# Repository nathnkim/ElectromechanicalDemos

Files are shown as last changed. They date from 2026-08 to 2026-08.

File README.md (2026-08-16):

# Base excitation demo assembly and test video:  https://www.youtube.com/watch?v=d6ixO5XXAhE
# Position control assembly and test video: https://www.youtube.com/watch?v=w2qYwhUiyq8
This repo contains the source files and documentation for the SDoF demo platform that I originally designed and built for MECHENG 360 at the University of Michigan - Ann Arbor, under Dr. Jeffrey Koller.

The SDoF demo platform consists of a brushed DC motor on an aluminum testbed which can be swapped between a mass-spring-damper base excitation demo and linear position control PID tuning demo.

Drive base:


Power module:


Base excitation demo:


Linear position control demo:


This version of SDoF is a good start, but it could benefit from further iteration. Suggested next steps to improve the demo are listed in the "Next Steps" document in this directory. This documentation was originally hosted in Google Drive, so many of the documentation files exist as Word doc files as an artifact of the download from drive > upload to Github migration. I've included full CAD models of the original design, complete with a comprehensive bill of materials and part numbering scheme. I've also included the code that ran on these demos (definitely some bugs to work out) as well as wiring diagrams.

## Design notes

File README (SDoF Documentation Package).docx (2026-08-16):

Nathan Kim (nathnkim@umich.edu)

2/6/2024

This directory contains the documentation for the SDoF demo platform originally designed and built for MECHENG 360 at the University of Michigan - Ann Arbor, under Dr. Jeffrey Koller.

This version of SDoF is a good start, but could benefit from further iteration. Suggested next steps to improve the demo are listed in the “Next Steps” document in this directory. I’ve included full CAD models of the original design, complete with a comprehensive bill of materials and part numbering scheme. I’ve also included the code that ran on these demos (definitely some bugs to work out) as well as wiring diagrams. To cover assembly of the demos, I made a couple of videos in the “How to Build SDoF” folder which, as well as a fastener guide document that shows what bolt goes where.

Definitely feel free to reach out to me at nathnkim@umich.edu if anything is confusing!

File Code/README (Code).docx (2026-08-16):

sdof_freq_sweep.ino is the program that runs on the frequency sweep module, and sdof_control.ino is the program that runs on the control module. Both run on an Arduino Micro (https://store.arduino.cc/products/arduino-micro). sdof_control.ino needs some work to write the interrupt service routines to safe the demo if the pointer slams into either of the limit switches. Additionally, the controls demo is currently pretty buggy for reasons unknown- perhaps the code needs to be made more robust.

To edit these files, and upload them to the boards, I recommend using the Arduino IDE (https://www.arduino.cc/en/software). Download the FOLDERS of the code as they are in this directory, since the Arduino IDE requires that .ino files be in a folder with the same name in order to open them.

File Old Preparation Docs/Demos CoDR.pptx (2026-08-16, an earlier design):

## ME 360 Teaching Demos

Conceptual Design Review
Nathan Kim

Note - this deck was a preliminary iteration of ideas presented to the FA2023 instructional team for feedback. Saving it for posterity; note the design has changed quite a bit since this presentation was delivered.
-Nathan Kim 1/4/2024

## Frequency Response Demo - “ME 360 Single Degree of Freedom”

Overview:
- Single degree of freedom mass-spring-damper with base excitation
- Motion input provided by slider-crank mechanism driven by 12V DC motor
- User input:
  - Knob to vary excitation frequency
  - Easy to change masses, springs with different constants, dampers with different constants
Learning Objectives:
- Students can vary system parameters and sweep frequencies in a very tactile way to build an intuitive understanding of second order system frequency response

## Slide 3

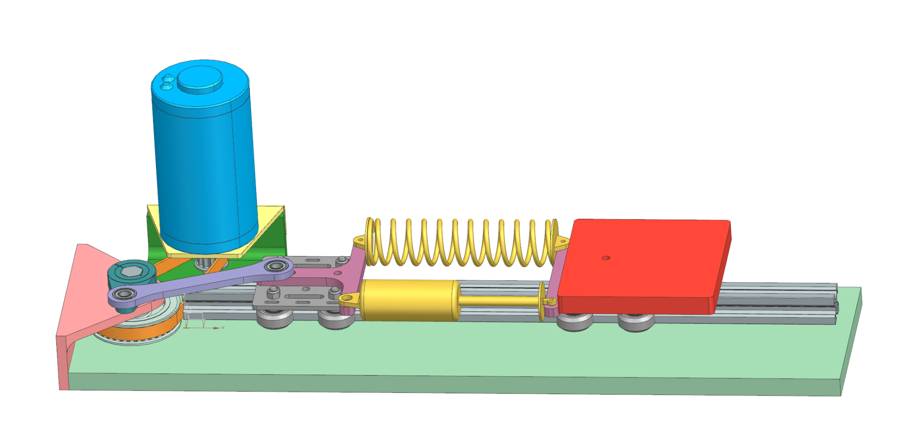
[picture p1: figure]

20” long x 5” wide, 0.5” thick Al plate base with plenty of room to be clamped to a table

Drive system is modular; belt is tensionable through pivoting of this module

SDoF Mechanical Assembly

System parameters fastened with bolts + wingnuts for relative ease of adjustment

Square mass plates can be stacked

Performance RC car springs and dampers

Al extrusion linear rail + gantry plates with ball bearings constrain motion along DoF

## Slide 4

SDoF Mechanical Assembly

Pocketed base plate allows for underside hardware mounting while still sitting flush on a surface

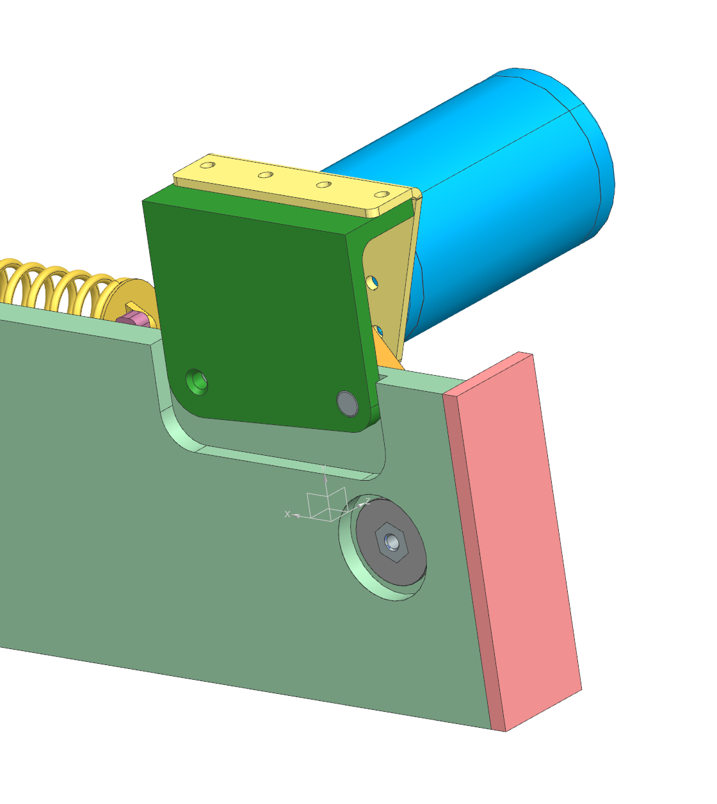
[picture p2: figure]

Precision dowel pin provides pivot point for drive module, allowing for belt tensioning

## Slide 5

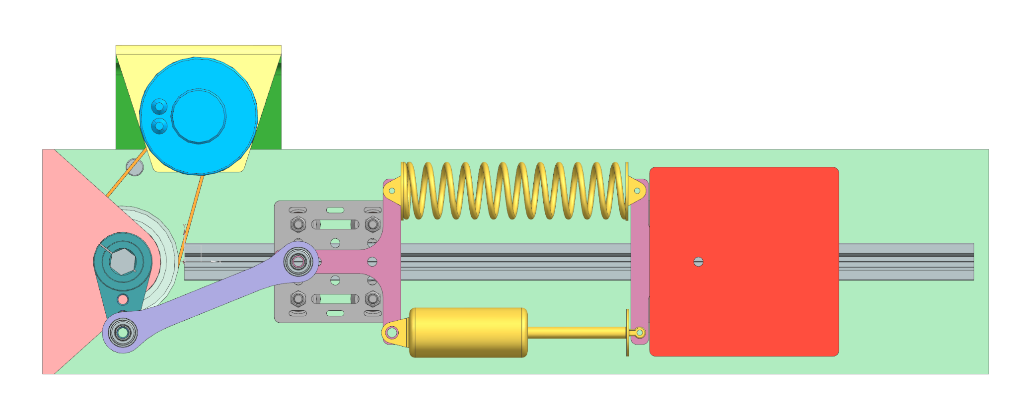
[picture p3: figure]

SDoF Mechanical Assembly

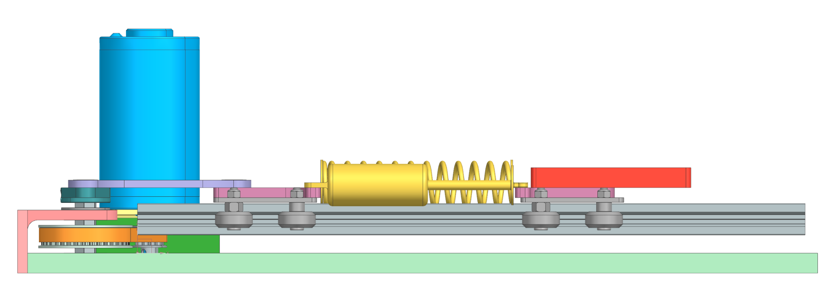
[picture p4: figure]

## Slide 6

SDoF Mechanical Assembly

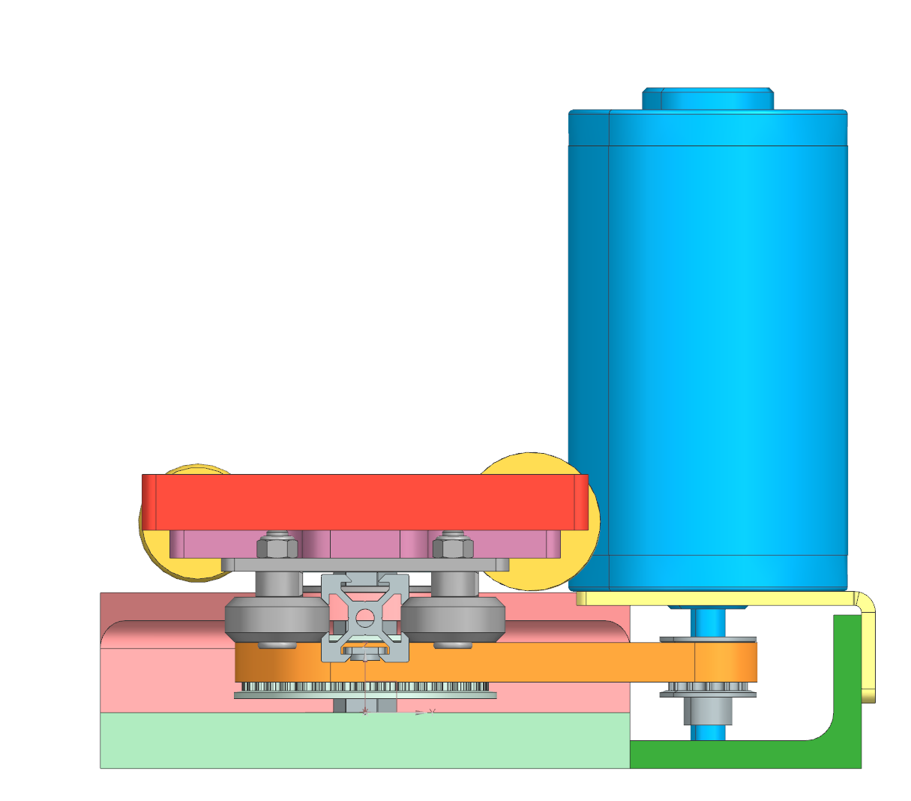
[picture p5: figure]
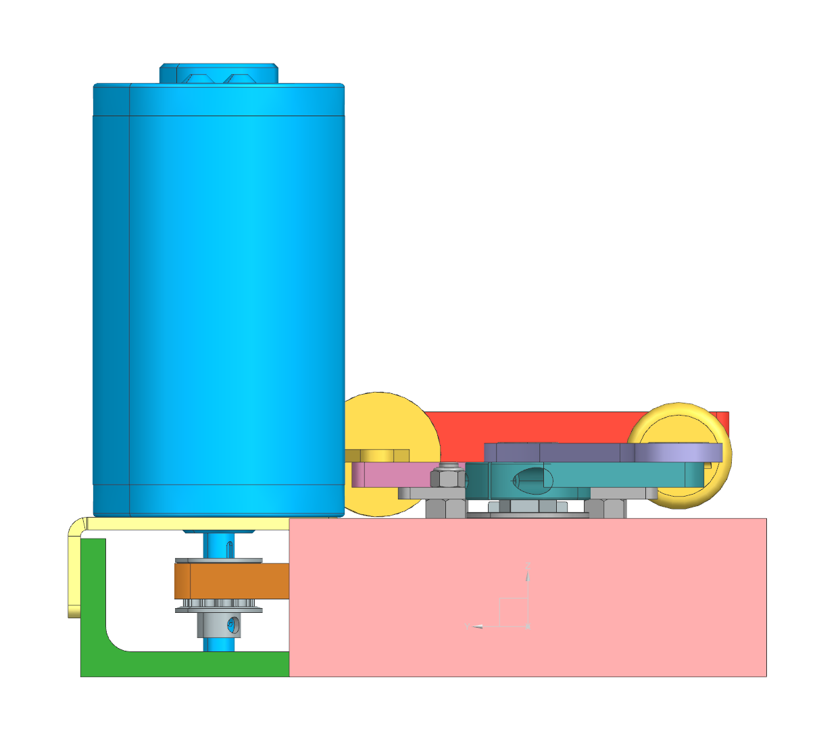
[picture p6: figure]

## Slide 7

All electronic components are available as generics on Amazon

SDoF Electronics

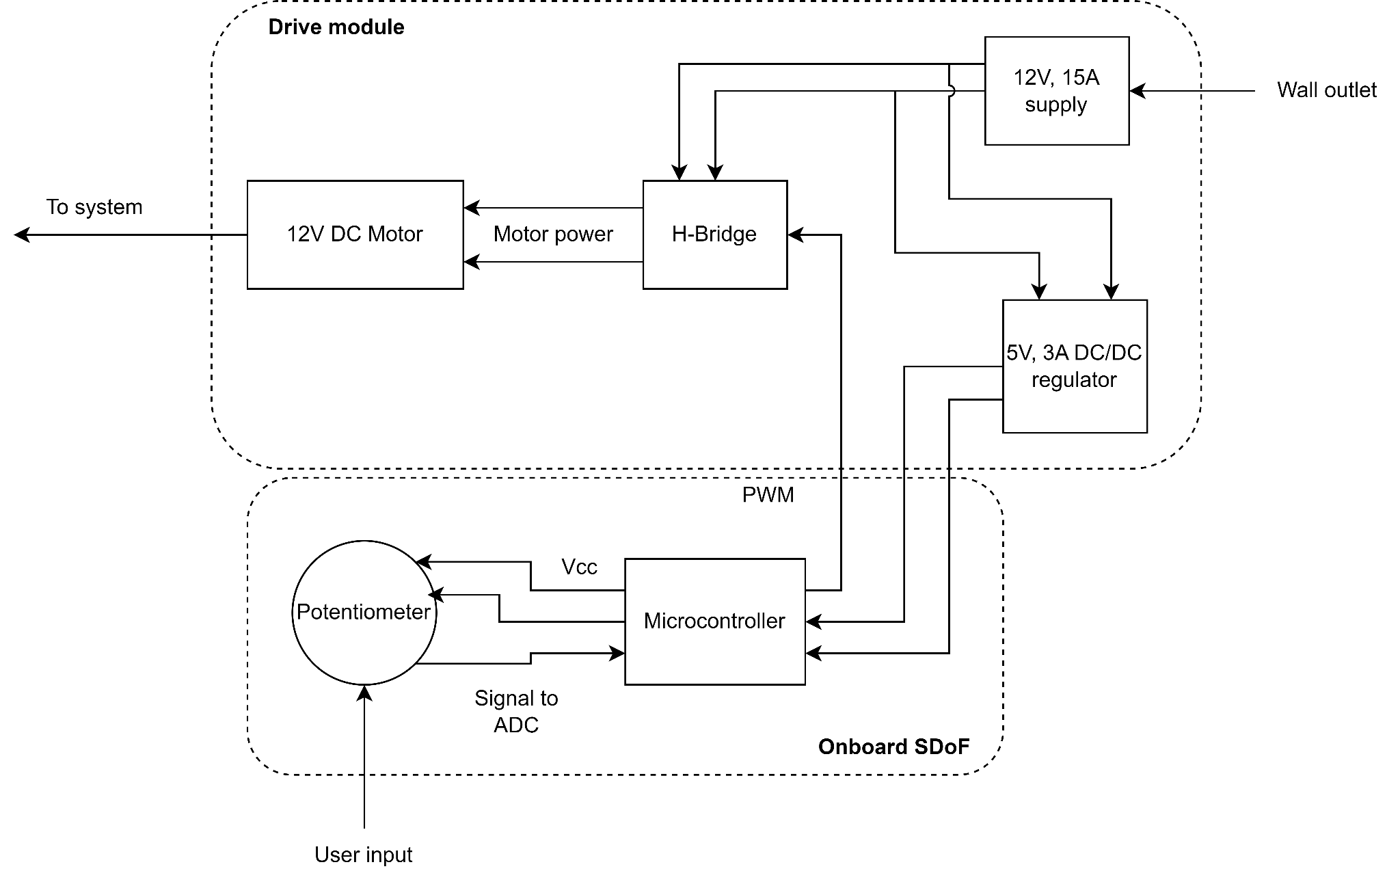
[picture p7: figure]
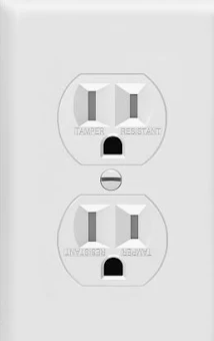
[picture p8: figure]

Drive module allows drop-in compatibility with control box demo

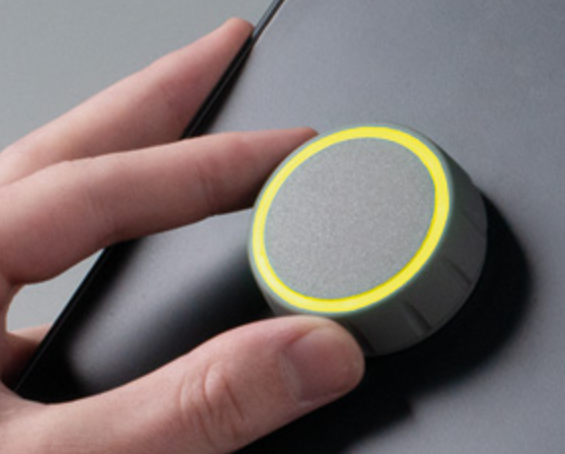
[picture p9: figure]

Enclosures will be designed/fabricated after function is verified

## PID Controller Demo - “ME 360 Point-a-Tron” - awaiting better alt

Overview:
- Single degree of freedom position control
- Drive module shared with SDoF demo
- User input:
  - Knobs to adjust controller gains
  - Hand positioning of reference position
Learning Objectives:
- Students can vary controller gains in a tactile way to build an intuitive understanding of how PID gains affect controller performance

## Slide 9

Exact same drive base as SDoF, so only 1 needs to be built

Point-a-Tron Mechanical Assembly

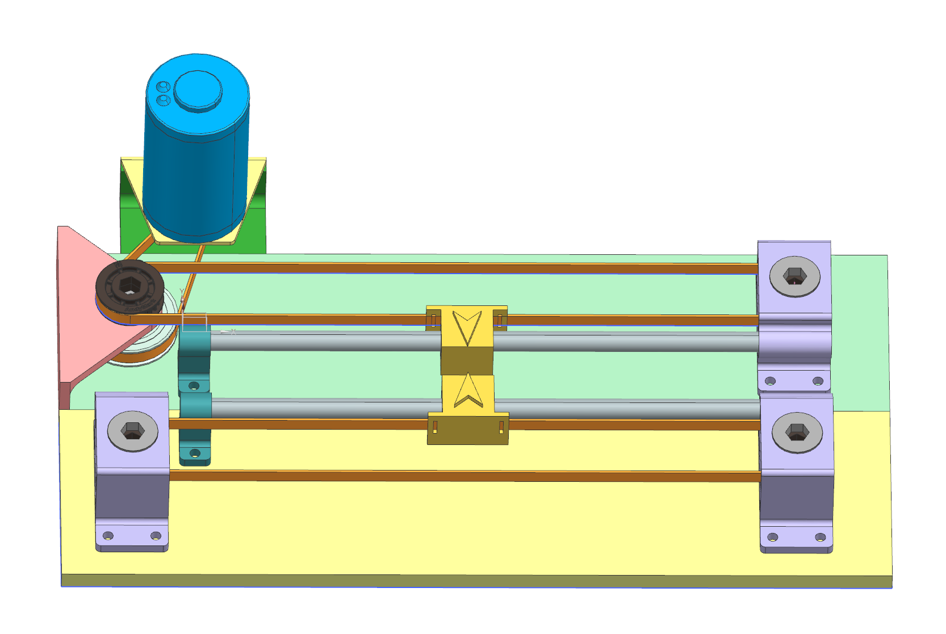
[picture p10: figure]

Belt-driven 3D printed pointer rides motion rail

Low loads means all support structures can be 3D printed

Reference input rail structure is a mirror of controlled output structure

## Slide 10

Point-a-Tron Mechanical Assembly

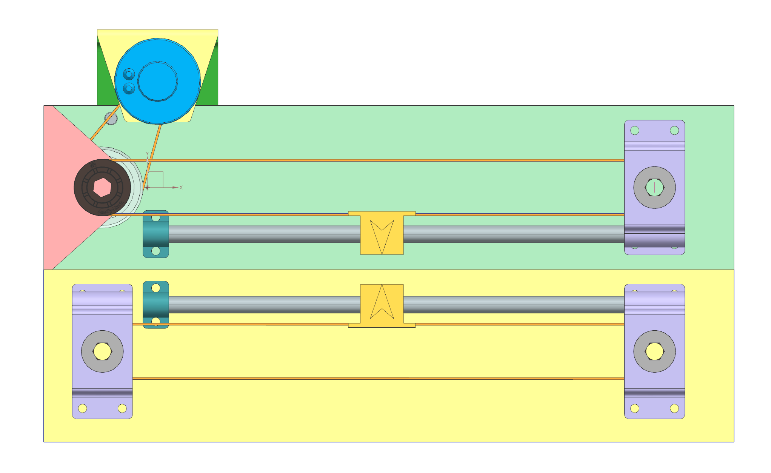
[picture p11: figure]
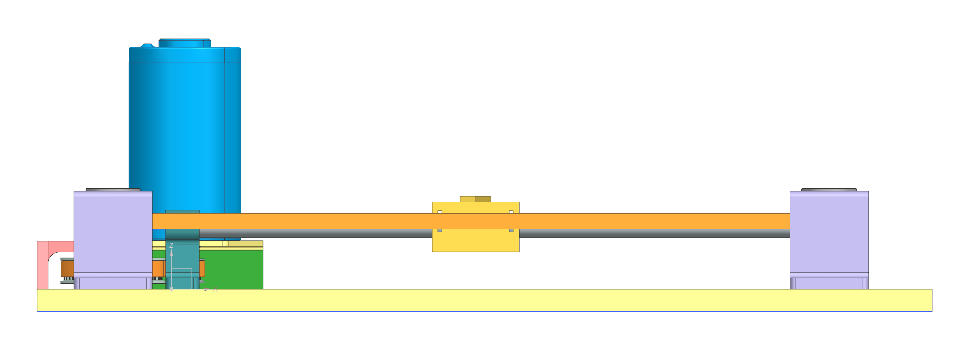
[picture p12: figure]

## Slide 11

Point-a-Tron Mechanical Assembly

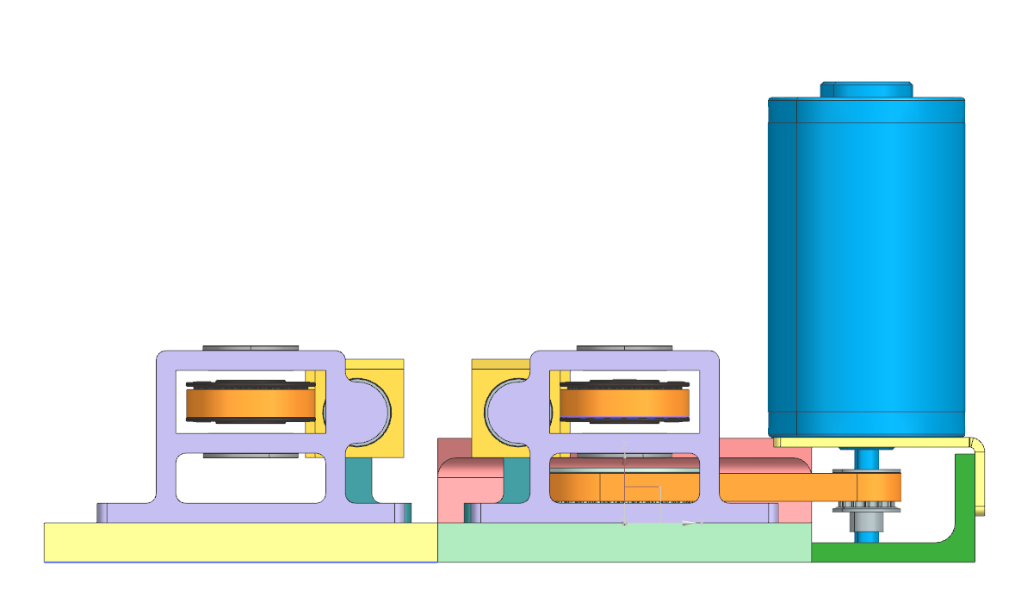
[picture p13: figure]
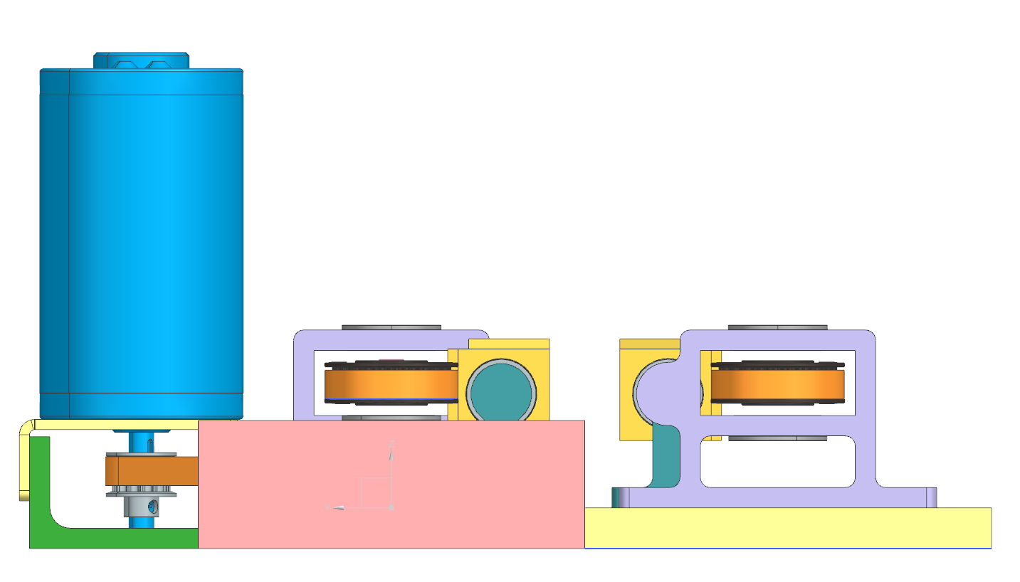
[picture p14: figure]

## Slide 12

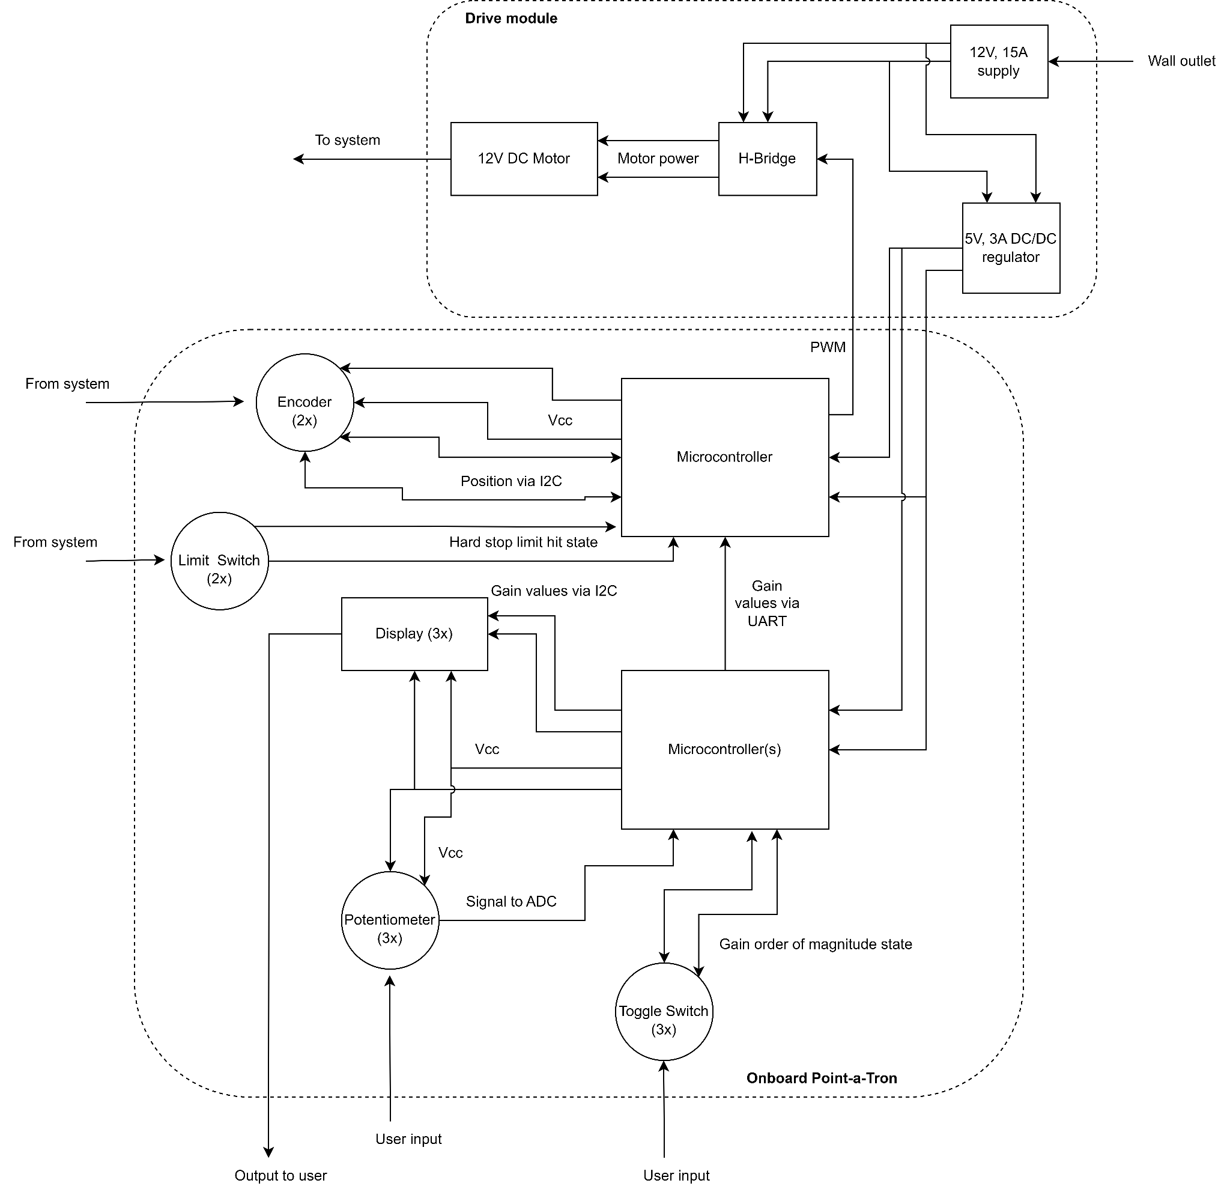
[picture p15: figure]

Point-a-Tron Electronics

Lots of displays to drive, inputs to deal with, so baselining multiple microcontrollers- might be able to get around this by daisy-chaining I2C

Enclosures will be designed/fabricated after function is verified

## Path Forward

- Incorporate feedback
- Finishing touches on CAD
  - Final hole patterns and fastener sizing
  - Higher fidelity spring/damper models
  - Switch/knob mounting structures
- Cut a BoM + get parts ordered- order ready to go out by next Friday for SDoF parts

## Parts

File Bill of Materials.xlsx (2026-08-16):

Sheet: Start Here
Introduction
This sheet contains the Bill of Materials (BOM) for the first revision design of SDoF demonstration platform. Each major assembly has its own sheet tab below. The CAD is split into major assemblies which include the drive base, which is common between the frequency and controller demos (which themselves are major assemblies) as well as the power module, which is the power supply that feeds the drive base. These sheets contain the individual bills of material for each major assembly, using part numbers that match CAD, and the sheet tab names include the CAD part number/filename as well. COTS parts have numbers that allow you to trace back the actual part to the supplier by simply copy/ pasting the part number into your url bar and also have purchase links listed. The sheets also include manufacturing notes where applicable. Note SDOF-FREQ-A01 and SDOF-CTRL-A01 contain subassemblies, which exist due to how the electronics are modularized. Their sheets contain SDOF-FREQ-A02 and SDOF-CTRL-A02 respectively, and both include SDOF-A01, all of which have their own wiring schematics. Also note that there are common parts (fasteners, connectors, etc) between major assemblies. These kinds of components often come in packs, so if you buy a pack for one assembly, it may cover the qty needed for other asssemblies. Double check the QTY columns when buying packs. Similarly, there are parts that use the same stock, like the axles. For these, one long piece of stock can be used to make every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
How to interpret part numbers: Commercial-off-the-shelf (COTS): SUPPLIER-SUPPLIERPART. Items that were bought and used more or less as is. -> Example: the motor is AndyMark product AM-0255, so in this scheme its PN is ANDYMARK-AM-0255 Custom designed/built parts: ASSEMBLY-FILETYPE#(L/R). Parts that were custom designed and built. Part filetypes are either assemblies (contain components, -AXXX tag) or components (single solid body, -CXXXX tag). If the part has a mirror pair, it well be designated by the L or R tag for left or right. -> Example: the drive base plate is in the SDOF assembly, is a component file, and is component #1, so in this scheme its PN is SDOF-C01. -> Example: the major assembly for the power module is the SDOF-PWR assmebly, is an assembly file, and is the top level assembly (#1), so in this scheme its PN is SDOF-PWR-A01 -> Example: the control module subassembly is in the SDOF-CTRL assembly, it is an assembly file, and is the first subassembly (#2), so in this scheme its PN is SDOF-CTRL-A02 -> Example: the spring end rotation constraint is in the SDOF-FREQ assembly, is a component file, is component #8, and has a mirror, so in this scheme the mirror pair PNs are SDOF-FREQ-C08L and SDOF-FREQ-C08R.
Major Assemblies

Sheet: SDOF-A01 (Drive Base)
Drive Base (PN: SDOF-A01)
Part Description | Part Number (PN) | QTY (per assembly) | Included in CAD for SDOF-A01? | Source | MFG notes
Base plate | SDOF-C01 | 1 | Y | Stock: https://www.mcmaster.com/8975K217-9140T109/ | Custom machined; manual mill, end holes match drilled using SDOF-C02
Crankshaft bracket | SDOF-C02 | 1 | Y | Stock: https://www.mcmaster.com/8982K63-8982K631/ | Custom machined; manual mill + hand shaped
Motor bracket-base plate bracket | SDOF-C03 | 1 | Y | Stock: https://www.mcmaster.com/8982K63-8982K631/ | Custom machined; manual mill + hand shaped
Crankshaft | SDOF-C04 | 1 | Y | Stock: https://www.andymark.com/products/1-2-in-7075-aluminum-hex-shaft-stock?Length=3%20ft.%20(am-2291-3)&quantity=1 | Custom machined; manual lathe
1/8" hex spacer | SDOF-C05 | 3 | Y | 3D printed PLA | 3D printed PLA
Cable-base mount | SDOF-C06 | 2 | Y | 3D printed PLA | 3D printed PLA
Jack-H-bridge bracket | SDOF-C07 | 1 | Y | 3D printed PLA | 3D printed PLA
XT60-H-bridge bracket | SDOF-C08 | 1 | Y | 3D printed PLA | 3D printed PLA
Cable-H-bridge mount | SDOF-C09 | 1 | Y | 3D printed PLA | 3D printed PLA
Drive wire cover | SDOF-C10 | 1 | Y | 3D printed PLA | 3D printed PLA
Name plate base | SDOF-C11 | 1 | No, but file exists | 3D printed PLA | 3D printed PLA - ditched this as I didnt like the way it looked in real life
Name plate | SDOF-C12 | 1 | No, but file exists | From scrap | Laser cut/engraved- ditched this as I didnt like the way it looked in real life
Drive cable | SDOF-C13 | 1 | N | From scrap | Hacked together from an old USB cable, spliced in female JST SMR-04V connector (not in CAD)
1/4-20 socket cap machine screw | MCMASTER-92949A539 | 14 | N - see fastener install guide | COTS: https://www.mcmaster.com/92949A539/
1/4 bore washer | MCMASTER-90107A029 | 1 | N - see fastener install guide | COTS: https://www.mcmaster.com/90107A029/
M3 machine screw + nut pairs | AMAZON-B01NBOCXHE | 2 | N - see fastener install guide | COTS: https://www.amazon.com/gp/product/B01NBOCXHE/ref=ppx_yo_dt_b_asin_title_o01_s00?ie=UTF8&th=1
Dowel pin | MCMASTER-98381A619 | 1 | Y | COTS: https://www.mcmaster.com/98381A619/
1/2" hex bearings | ANDYMARK-AM-2986 | 2 | Y | COTS: https://www.andymark.com/products/0-5-in-hex-id-1-125-in-od-shielded-flanged-bearing-fr8zz-hexhd
Motor | ANDYMARK-AM-0255 | 1 | Y | COTS: https://www.andymark.com/products/2-5-in-cim-motor
Motor shaft key | ANDYMARK-AM-1121 | 1 | N - see fastener install guide | COTS: https://www.andymark.com/products/2x2x10-mm-machine-key-steel
Motor mount bracket | ANDYMARK-AM-4244 | 1 | Y | COTS: https://www.andymark.com/products/bearing-and-motor-mount-bracket
Motor mount bolts | MCMASTER-91251A342 | 2 | N - see fastener install guide | COTS: https://www.mcmaster.com/91251A342/
Belt | ANDYMARK-AM-4902 | 1 | Y | COTS: https://www.andymark.com/products/9-mm-wide-5-mm-pitch-htd-timing-belts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
Pinion | ANDYMARK-AM-3263 | 1 | Y | COTS: https://www.andymark.com/products/12-tooth-5mm-htd-cim-bore-pulley-with-flanges
Drive pulley | VEX-217-3231 | 1 | Y | COTS: https://www.vexrobotics.com/htdpulleys.html#attr-vex_drawings
H-bridge | AMAZON-B07SH6BX97 | 1 | Y | COTS: https://www.amazon.com/gp/product/B07SH6BX97
XT60 connector | AMAZON-B07233RVL6 | 1 | Y | COTS: https://www.amazon.com/Female-Bullet-Connectors-Shrink-Battery/dp/B07233RVL6/ | Had to carve off some of the embossed symbols to fit the brackets with an exacto knife
Barrel Jack | AMAZON-B091PS6XQ4 | 1 | Y | COTS: https://www.amazon.com/gp/product/B091PS6XQ4/
Not included in BoM:
Assorted wire/heat shrink for drive cable installation

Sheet: SDOF-PWR-A01 (Power Module)
Power Module (PN: SDOF-PWR-A01)
Part Description | Part Number (PN) | QTY (per assembly) | Included in CAD for SDOF-PWR-A01? | Source | MFG notes
12v power supply | AMAZON-B08LDC41B6 | 1 | Y | COTS: https://www.amazon.com/Universal-Regulated-Switching-Converter-Transformer/dp/B08LDC41B6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 | Used crimp spade connectors for the screw terminal connections
Toggle switch | AMAZON-B078KBC5VH | 1 | Y | COTS: https://www.amazon.com/Nilight-Rocker-Toggle-Switch-Waterproof/dp/B078KBC5VH?sp_csd=d2lkZ2V0TmFtZT1zcF9hdGY
12v-5v DC-DC converter | AMAZON-B07Y2V1F8V | 1 | Y | COTS: https://www.amazon.com/Converter-Voltage-Waterproof-Regulator-Step-Down/dp/B07Y2V1F8V
Inline fuse holder | AMAZON-B08K3M554K | 1 | N - see wiring schematic for placement | COTS: https://www.amazon.com/dp/B08K3M554K?ref=ppx_yo2ov_dt_b_product_details&th=1
10A blade fuse | AMAZON-B07G33XCHM | 1 | N - see wiring schematic for placement | COTS: https://www.amazon.com/dp/B07G33XCHM?psc=1&ref=ppx_yo2ov_dt_b_product_details
Power supply cover | SDOF-PWR-C01 | 1 | Y | 3D printed PLA | 3D printed PLA, used cyanoacrylate to glue M3 nuts into recesses before assembly. Took some fiddling to get nice mate between this part and the power supply.
Small cable gland | SDOF-PWR-C02 | 2 | Y | 3D printed PLA | 3D printed PLA
Large cable gland | SDOF-PWR-C03 | 1 | Y | 3D printed PLA | 3D printed PLA
XT60 connector (male) | AMAZON-B07233RVL6 | 1 | N - see wiring schematic for placement | COTS: https://www.amazon.com/Female-Bullet-Connectors-Shrink-Battery/dp/B07233RVL6/
DC barrel jack (male) | AMAZON-B08SJM2G52 | 1 | N - see wiring schematic for placement | COTS: https://www.amazon.com/Socket-Threaded-Connector-Adapter-Dustproof/dp/B08SJM2G52/
M3 machine screw + nut pairs | AMAZON-B01NBOCXHE | 3 | N - see fastener guide | COTS: https://www.amazon.com/gp/product/B01NBOCXHE/ref=ppx_yo_dt_b_asin_title_o01_s00?ie=UTF8&th=1
Not included in BoM
Mounting hardware for the toggle switch (came included with the component purchased)
Male 110V wall plug to wire in, I bought this at a hardware store

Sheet: SDOF-FREQ-A01 (Frequency Respon
Frequency Response Demo (PN: SDOF-FREQ-A01)
Part Description | Part Number (PN) | QTY (per assembly) | Included in CAD for SDOF-FREQ-A01? | Source | MFG notes
Drive base | SDOF-A01 | 1 | Y | Custom assembly | See SDOF-A01 sheet and documentation
Crank | SDOF-FREQ-C01 | 1 | Y | Scrap steel & shaft collar: https://www.mcmaster.com/7552K5/ | Shaped and welded steel plate to shaft collar, then drilled and tapped holes
Connecting rod | SDOF-FREQ-C02 | 1 | Y | Scrap stainless steel | Bored bearing seats on manual mill, shaped by hand
Spring/damper bracket | SDOF-FREQ-C03 | 2 | Y | Stock: https://www.mcmaster.com/89015K235/ | Lasercut from 0.125" thick 6061 sheet
Rail spacer | SDOF-FREQ-C04 | 2 | Y | Scrap aluminum | Shaped and drilled by hand
Crank-Connecting rod spacer | SDOF-FREQ-C05 | 1 | Y | 3D printed PLA | 3D printed PLA
Connecting rod-gantry plate spacer | SDOF-FREQ-C06 | 1 | Y | 3D printed PLA | 3D printed PLA
Spring end plate | SDOF-FREQ-C07 | 2 | Y | Scrap aluminum | Lasercut from 0.125" thick 6061 sheet
Left spring end rotation constraint | SDOF-FREQ-C08L | 1 | Y | 3D printed PLA | 3D printed PLA
Right spring end rotation constraint | SDOF-FREQ-C08R | 1 | Y | 3D printed PLA | 3D printed PLA
Bolt spacer | SDOF-FREQ-C09 | 4 | Y | 3D printed PLA | 3D printed PLA
Spring | AMAIN-PRO6275-00-Spring | 1 | Y | COTS: https://www.amainhobbies.com/proline-5-powerstroke-xt-shocks-pro6275-00/p479230 | Vendor PN is PRO6275-00, which comes with spring and damper integrated. Given "Spring" tag since whole shock disassembled to isolate the spring. CAD model is very approximate.
Damper | AMAIN-PRO6275-00-Damper | 1 | Y | COTS: https://www.amainhobbies.com/proline-5-powerstroke-xt-shocks-pro6275-00/p479230 | Vendor PN is PRO6275-00, which comes with spring and damper integrated. Given "Damper" tag since whole shock disassembled to isolate the damper. Two packs of this product were bough to have 4 dampers that could be filled with different viscosities of shock fluid (https://www.amainhobbies.com/team-losi-racing-silicone-shock-oil-six-pack-20-25-30-35-40-45wt-2oz-tlr74020/p252365). Used a youtube video to figure out how to fill the dampers with oil and bleed them properly- search "how to bleed and fill RC car shocks". CAD model is very approximate.
1/4-20 socket cap machine screw | MCMASTER-92949A539 | 8 | N - see fastener install guide | COTS: https://www.mcmaster.com/92949A539/
M3 machine screw + nut pairs | AMAZON-B01NBOCXHE | 2 | N - see fastener install guide | COTS: https://www.amazon.com/gp/product/B01NBOCXHE/ref=ppx_yo_dt_b_asin_title_o01_s00?ie=UTF8&th=1
M5 socket cap machine screw | MCMASTER-92095A218 | 2 | N - see fastener install guide | COTS: https://www.mcmaster.com/92095A218/ | I had to chop em down a bit smaller on the bandsaw to fit. Note- I bought these from Stadium Hardware in Ann Arbor, much cheaper to buy 2 than a pack on McMaster
M5 threaded plates | OPENBUILDS-536-Pack | 2 | N - see fastener install guide | COTS: https://openbuildspartstore.com/tee-nuts-m5-10-pack/
Gantry plate assembly | OPENBUILDS-1195-Set | 2 | Y | COTS: https://openbuildspartstore.com/v-slot-gantry-kit-20mm/ | Comes in a little kit, found a youtube video to show how to build. I tapped some of the holes in the top plate 1/4-20 to bolt spring/damper brackets on.
Extrusion rail | OPENBUILDS-150-LP | 1 | Y | COTS: https://openbuildspartstore.com/v-slot-20x20-linear-rail/ | Precision version of your normal 80/20 extrusion
Connecting rod bearing | MCMASTER-60355K246 | 2 | Y | COTS: https://www.mcmaster.com/60355K246/
Frequency module | SDOF-FREQ-A02 | 1 | Y | SEE BELOW FOR SUBASSEMBLY PARTS
Frequency Module (PN: SDOF-FREQ-A02) - Subassembly within SDOF-FREQ-A01
Part Description | Part Number (PN) | QTY (per assembly) | Included in CAD for SDOF-FREQ-A02? | Source | MFG notes
Control module base | SDOF-FREQ-C10 | 1 | Y | 3D printed PLA | 3D printed PLA
Control module lid | SDOF-FREQ-C11 | 1 | Y | 3D printed PLA | 3D printed PLA
Potentiometer + knob pair | AMAZON-B09897HR3C | 1 | Y- knob not modeled in CAD | COTS: https://www.amazon.com/Taiss-Potentiometer-Washers-Different-Aluminum/dp/B09897HR3C
Arduino Micro | AMAZON-B01N1MJYK3 | 1 | Y | COTS: https://www.amazon.com/dp/B01N1MJYK3/ref=twister_B09TRPJVK6?_encoding=UTF8&psc=1
JST SMP-04V connector | AMAZON-B083GQHG5R | 1 | Y | COTS: https://www.amazon.com/gp/product/B083GQHG5R/ref=ppx_yo_dt_b_asin_title_o02_s00?ie=UTF8&th=1 | Removed one of the pins since module only needs 4 connections
Not included in BoM:
Assorted wire/heat shrink for drive cable installation
Shock oil for filling the dampers: https://www.amainhobbies.com/team-losi-racing-silicone-shock-oil-six-pack-20-25-30-35-40-45wt-2oz-tlr74020/p252365

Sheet: SDOF-CTRL-A01 (PID Controller D
PID Controller Demo (PN: SDOF-CTRL-A01)
Part Description | Part Number (PN) | QTY (per assembly) | Included in CAD for SDOF-CTRL-A01? | Source | MFG notes
Drive base | SDOF-A01 | 1 | Y | Custom assembly | See SDOF-A01 sheet and documentation
Pulley tower | SDOF-CTRL-C01 | 1 | Y | 3D printed PLA | 3D printed PLA- 2 sections glued together with cyanoacrylate for optimized print orientation - CAD file contains these sections as 2 separate bodies
Base rod support | SDOF-CTRL-C02 | 1 | Y | 3D printed PLA | 3D printed PLA- 3 sections glued together with cyanoacrylate for optimized print orientation - CAD file contains these sections as 3 separate bodies
Driven pointer | SDOF-CTRL-C03 | 1 | Y | 3D printed PLA | 3D printed PLA
Input pointer | SDOF-CTRL-C04 | 1 | Y | 3D printed PLA | 3D printed PLA
Limit switch extender | SDOF-CTRL-C05 | 2 | Y | 3D printed PLA | 3D printed PLA
Input axle, sensorless | SDOF-CTRL-C06 | 1 | Y | Stock: https://www.andymark.com/products/1-2-in-7075-aluminum-hex-shaft-stock?Length=3%20ft.%20(am-2291-3)&quantity=1 | Custom machined; manual lathe
Input axle, sensored | SDOF-CTRL-C07 | 1 | Y | Stock: https://www.andymark.com/products/1-2-in-7075-aluminum-hex-shaft-stock?Length=3%20ft.%20(am-2291-3)&quantity=1 | Custom machined; manual lathe
Driven axle, sensored | SDOF-CTRL-C08 | 1 | Y | Stock: https://www.andymark.com/products/1-2-in-7075-aluminum-hex-shaft-stock?Length=3%20ft.%20(am-2291-3)&quantity=1 | Custom machined; manual lathe
Pulley tower spacer | SDOF-CTRL-C09 | 2 | Y | 3D printed PLA | 3D printed PLA
Input thin spacer | SDOF-CTRL-C10 | 2 | Y | 3D printed PLA | 3D printed PLA
Input thick spacer | SDOF-CTRL-C11 | 2 | Y | 3D printed PLA | 3D printed PLA
Axle retaining clip | SDOF-CTRL-C12 | 2 | Y | Scrap aluminum | Custom machined; manual lathe and shaped by hand
Input pulley | SDOF-CTRL-C13 | 2 | Y | 3D printed from PLA | Each printed in 2 halves to avoid overhang
Sensor harness | SDOF-CTRL-C14 | 1 | N | From scrap | Hacked together out of old USB cables once again
1/4-20 socket cap machine screw | MCMASTER-92949A539 | 8 | N - see fastener install guide | COTS: https://www.mcmaster.com/92949A539/
1/4 bore washer | MCMASTER-90107A029 | 1 | N - see fastener install guide | COTS: https://www.mcmaster.com/90107A029/
M3 machine screw + nut pairs | AMAZON-B01NBOCXHE | 2 | N - see fastener install guide | COTS: https://www.amazon.com/gp/product/B01NBOCXHE/ref=ppx_yo_dt_b_asin_title_o01_s00?ie=UTF8&th=1
Drive pulley | ANDYMARK-AM-3403 | 2 | Y | COTS: https://www.andymark.com/products/24t-htd-pulley-1-2-in-hex-bore
1/2" hex bearings | ANDYMARK-AM-2986 | 6 | Y | COTS: https://www.andymark.com/products/0-5-in-hex-id-1-125-in-od-shielded-flanged-bearing-fr8zz-hexhd
Drive bushings | MCMASTER-6673K13 | 2 | Y | COTS: https://www.mcmaster.com/6673K13/
Drive belt | MCMASTER-7939K581-Drive | 1 | Y | COTS: https://www.mcmaster.com/7939K581/ | Cut to size, ziptied in place during final assembly
Input belt | MCMASTER-7939K581-Input | 1 | Y | COTS: https://www.mcmaster.com/7939K581/ | Cut to size, ziptied in place during final assembly
Linear motion rod - Drive | MCMASTER-6061K432-Drive | 1 | Y | COTS: https://www.mcmaster.com/6061K432/ | Cut to size by hand
Linear motion rod - Input | MCMASTER-6061K432-Input | 1 | Y | COTS: https://www.mcmaster.com/6061K432/ | Used right out of the bag
Magnetic encoder | AMAZON-B094F8H591-PCB | 2 | Y | COTS: https://www.amazon.com/Magnetic-Encoder-Induction-Measurement-Precision/dp/B094F8H591 | Magnets get glued into sensored axle pockets with cyanoacrylate, sensor boards needed to be sanded down to fit 3D printed parts
Diametrically polarized magnet | AMAZON-B094F8H591-Magnet | 2 | Y | COTS: https://www.amazon.com/Magnetic-Encoder-Induction-Measurement-Precision/dp/B094F8H591 | Comes included in pack with encoders
Limit switch | AMAZON-B07X142VGC | 2 | Y | COTS: https://www.amazon.com/dp/B07X142VGC?psc=1&ref=ppx_yo2ov_dt_b_product_details
Control Module (PN: SDOF-CTRL-A02) - Subassembly within SDOF-CTRL-A01
Part Description | Part Number (PN) | QTY (per assembly) | Included in CAD for SDOF-CTRL-A02? | Source | MFG notes
Test module base | SDOF-CTRL-C15 | 1 | Y | 3D printed PLA | 3D printed PLA
Test module midesction | SDOF-CTRL-C16 | 1 | Y | 3D printed PLA | 3D printed PLA
Test module lid | SDOF-CTRL-C17 | 1 | Y | 3D printed PLA | 3D printed PLA
I2C multiplexer | AMAZON-B0BTH8GCSC | 1 | N | COTS: https://www.amazon.com/dp/B0BTH8GCSC?psc=1&ref=ppx_yo2ov_dt_b_product_details | Just sort of shoved this inside the module
Arduino Micro | AMAZON-B01N1MJYK3 | 1 | Y | COTS: https://www.amazon.com/dp/B01N1MJYK3/ref=twister_B09TRPJVK6?_encoding=UTF8&psc=1
JST SMP-04V connector | AMAZON-B083GQHG5R | 1 | Y | COTS: https://www.amazon.com/gp/product/B083GQHG5R/ref=ppx_yo_dt_b_asin_title_o02_s00?ie=UTF8&th=1 | Removed one of the pins since module only needs 4 connections
Not included in BoM:
Assorted wire/heat shrink for drive cable installation

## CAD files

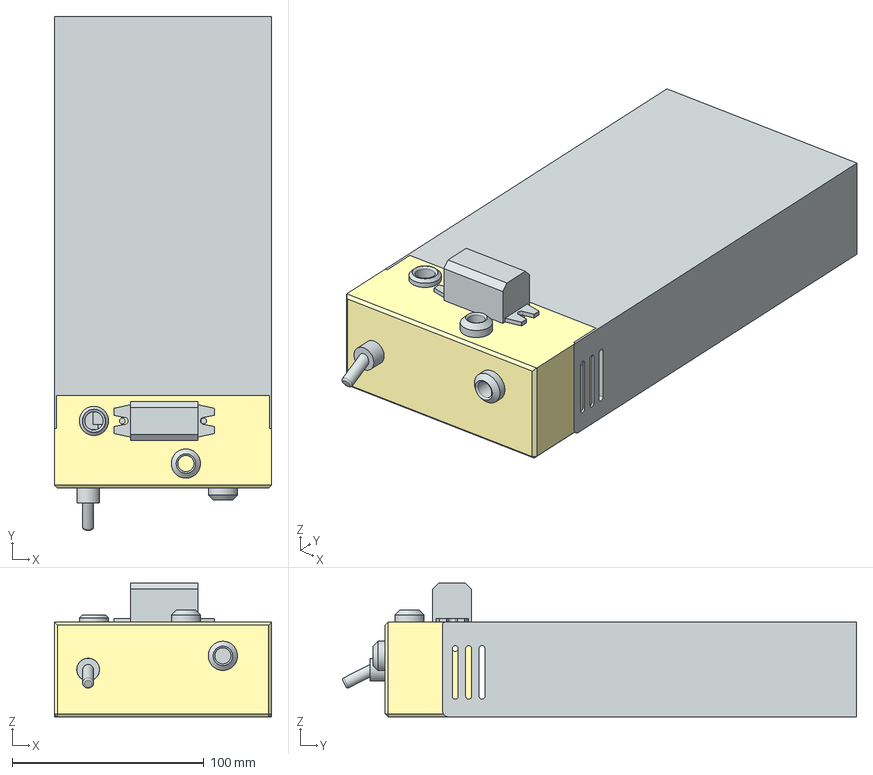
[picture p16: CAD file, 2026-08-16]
CAD/SDOF-PWR-A01.stp
113.3 x 268.1 x 69.8 mm
AMAZON-B08LDC41B6
SDOF-PWR-C01
SDOF-PWR-C02 x 2
SDOF-PWR-C03
AMAZON-B078KBC5VH
AMAZON-B07Y2V1F8V

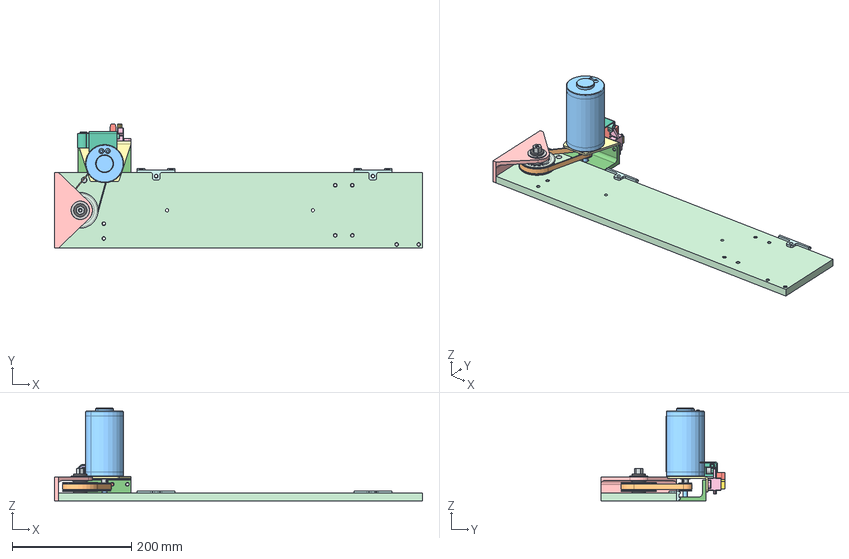
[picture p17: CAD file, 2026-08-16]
CAD/SDOF-A01.stp
616.0 x 208.4 x 154.9 mm
SDOF-C01
SDOF-C02
SDOF-C03
SDOF-C04
SDOF-C05 x 3
SDOF-C06 x 2
SDOF-C07
SDOF-C08
SDOF-C09
SDOF-C10
AMAZON-B07SH6BX97
AMAZON-B091PS6XQ4
AMAZON-B07233RVL6
ANDYMARK-AM-0255
ANDYMARK-AM-3263
ANDYMARK-AM-2986 x 2
ANDYMARK-AM-4244
VEX-217-3231
MCMASTER-98381A619
ANDYMARK-AM-4902

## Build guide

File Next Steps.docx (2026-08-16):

Here is a running list of next steps I have brainstormed for the SDoF demos:

Frequency Response Demo:

- Add vision targets (center of mass markers, scales) to enable image processing / characterization of frequency response
- Make mass attachment system more legit
- Swap in wingnuts or other fastener system to make spring and damper more easily swappable

Controls Demo:

- Look into swapping the belt system on the pointers to 2mm pitch, current belts are too big and stiff, causing smoothness issues and excess friction. Pulleys can be 3D printed.
- Currently there is code to detect crashes via the limit switches and interrupts, but no logic to handle them. Come up with interrupt service routine to reset system after limit switch crash
- Figure out how to add screens and knobs to the control module to allow adjustment of gains without code. I think this will require a second Arduino to manage driving the display and handling user input and sending the new gains to the control algorithm Arduino via the UART interface. Or just rip it up as it is now and put in a beefier microcontroller that can handle it all.
- Maybe make the whole thing a state machine so you can toggle between reference tracking mode and step input mode
- Pretty buggy as of last use in January of 2024, make it just work

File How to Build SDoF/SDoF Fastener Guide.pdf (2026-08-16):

# SDoF V1 Fastener Guide

## Fall 2023

¼-20 button head,
0.625” long

Flat washer

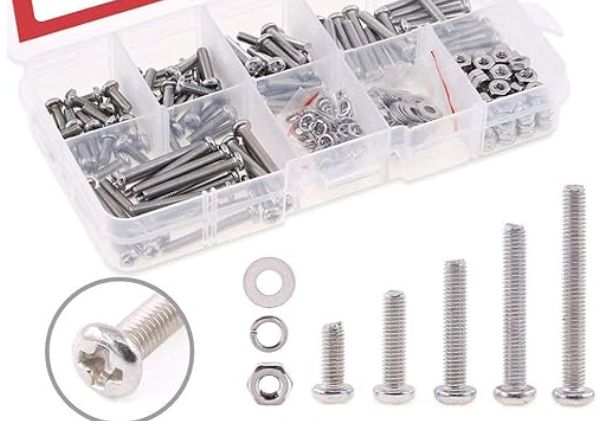
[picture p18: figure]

Assorted M3
machine screws

Common Fasteners used on SDoF*

*Small quantity of other fasteners are used in specific locations called out in following instructions

Part number:
MCMASTER-92949A539 | Part number:
| AMAZON-B01NBOCXHE

Part number:
MCMASTER-90107A029

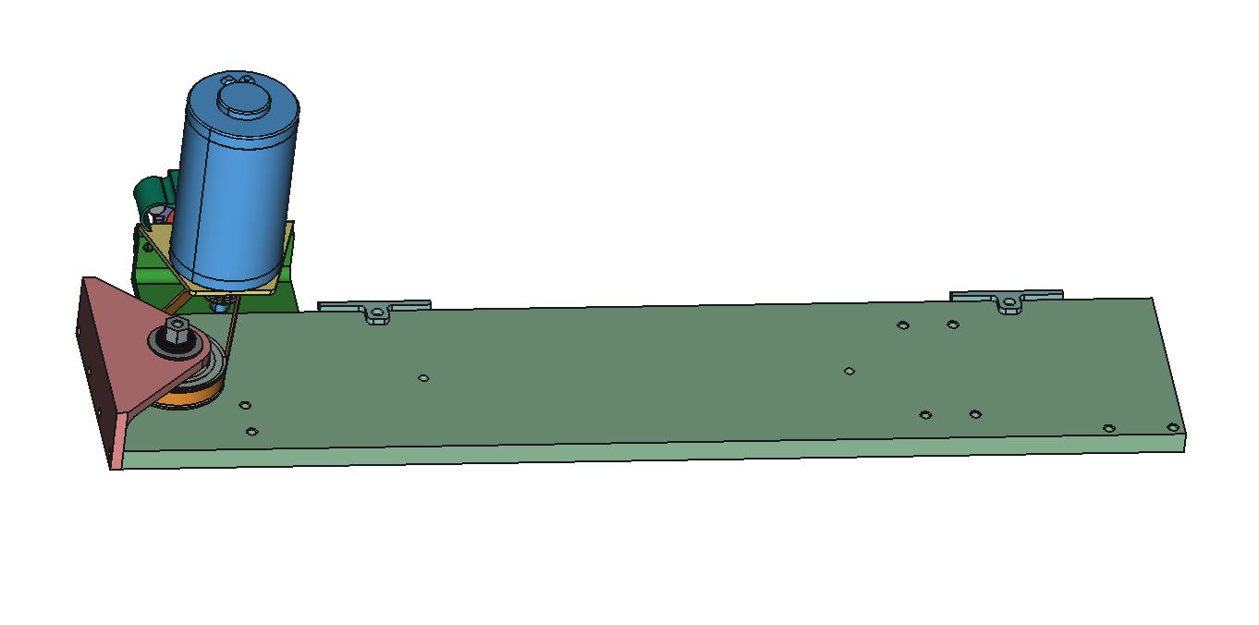
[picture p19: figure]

## SDOF-A01 | Drive Base

## SDOF-A01 | Crankshaft bracket and cable organizers

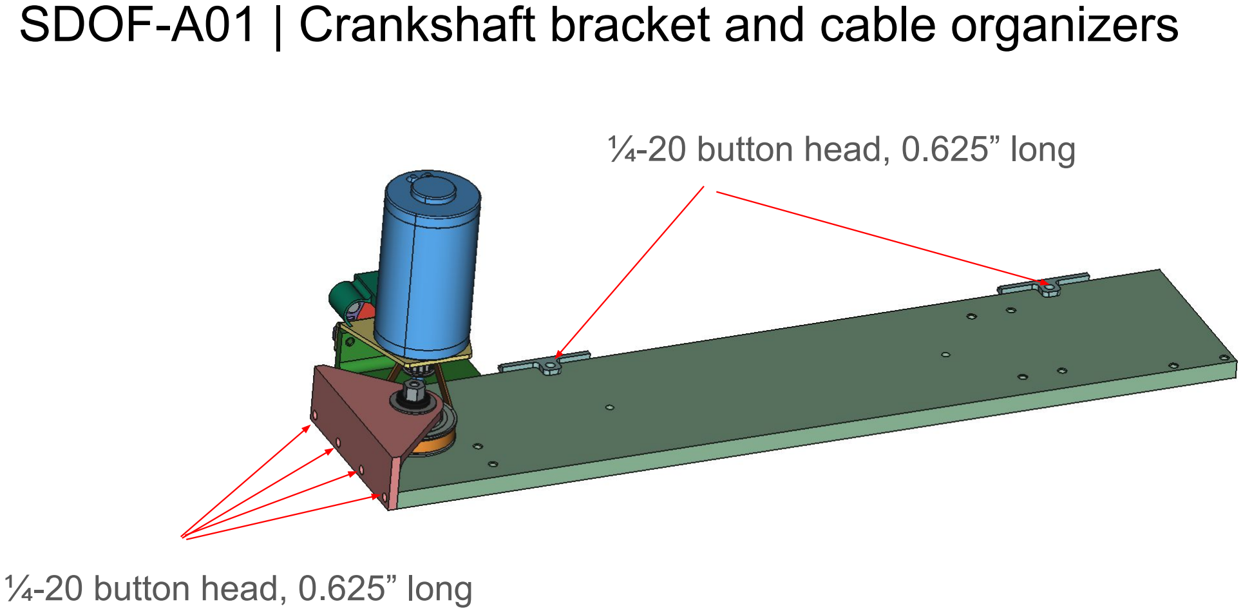
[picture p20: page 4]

¼-20 button head, 0.625” long

¼-20 button head, 0.625” long

## SDOF-A01 | Crankshaft bottom and belt tension

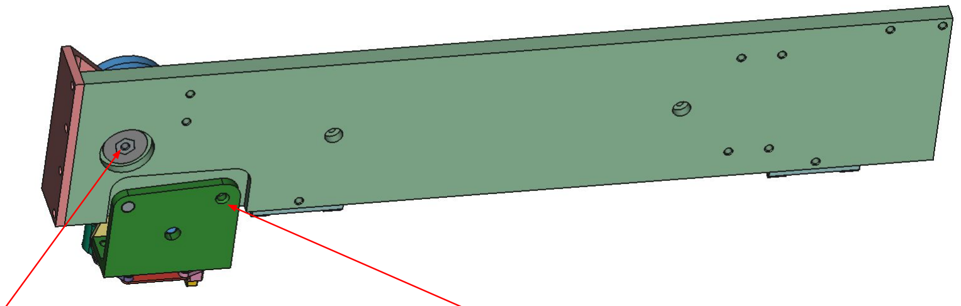
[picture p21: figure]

¼-20 button head, 0.625” long + flat washer | ¼-20 button head

## SDOF-A01 | Motor to motor bracket

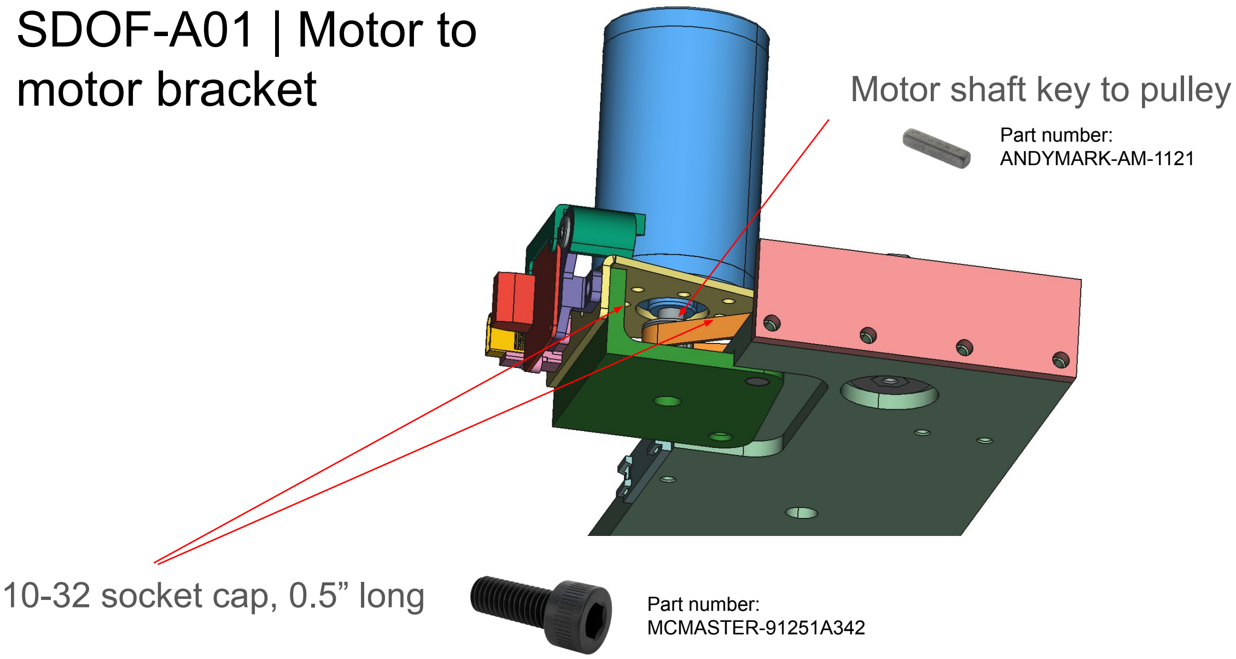
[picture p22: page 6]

10-32 socket cap, 0.5” long | Part number: MCMASTER-91251A342

Motor shaft key to pulley

| Part number:
ANDYMARK-AM-1121

## SDOF-A01 | 3 brackets to baseplate bracket

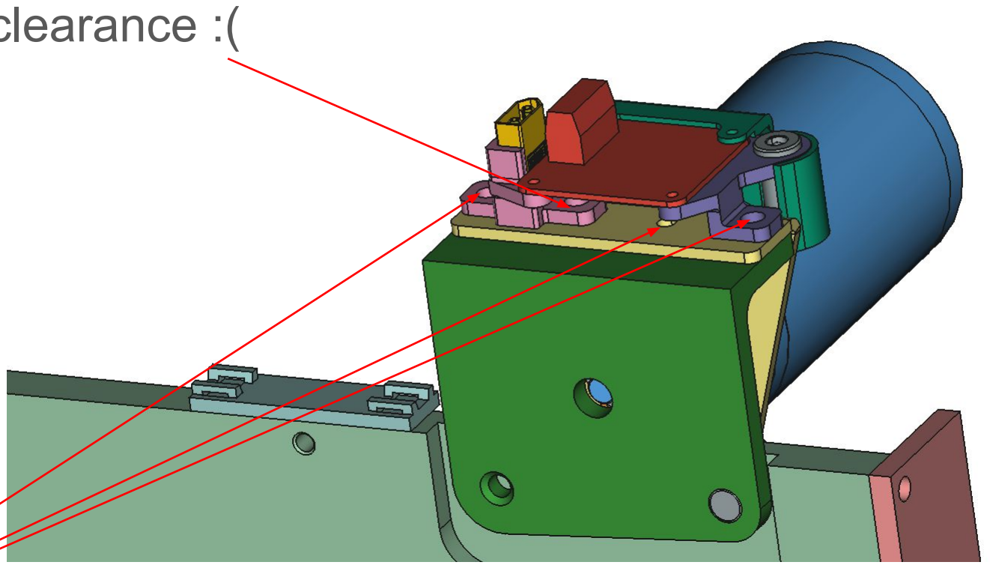
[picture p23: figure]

¼-20 button head, 0.625” long

Leave empty- no clearance :(

## SDOF-A01 | H-bridge, covers and cable inlet

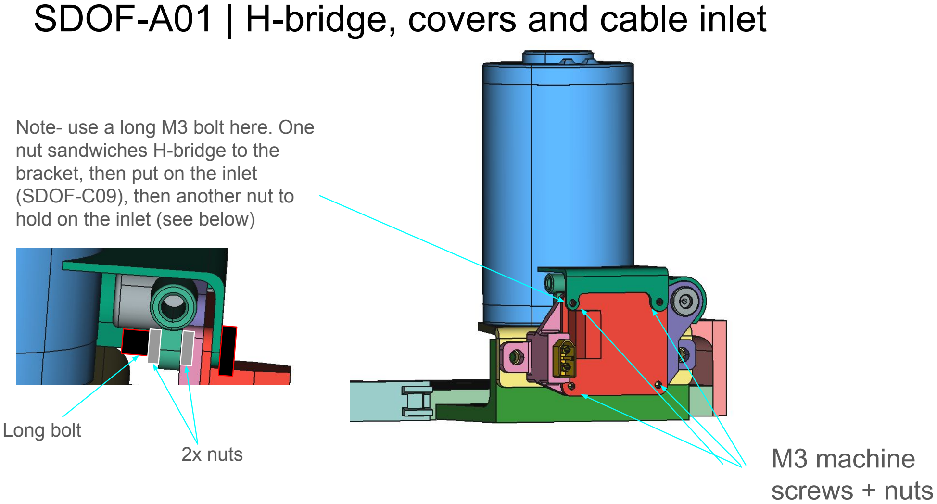
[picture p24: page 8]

M3 machine
screws + nuts

Note- use a long M3 bolt here. One nut sandwiches H-bridge to the bracket, then put on the inlet (SDOF-C09), then another nut to hold on the inlet (see below)

Long bolt
2x nuts

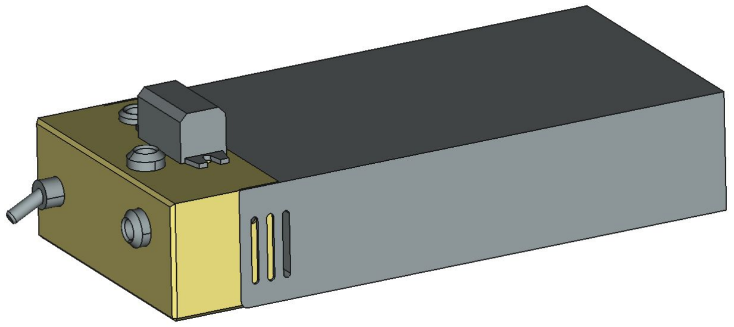
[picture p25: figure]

## SDOF-PWR-A01 | Power Module

## SDOF-PWR-A01 | Cover to power supply

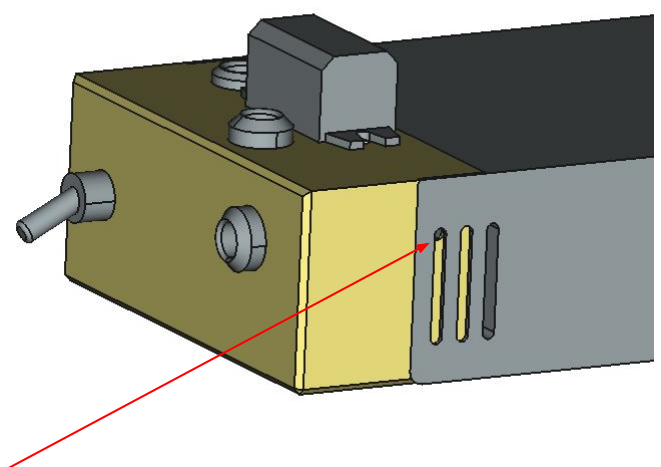
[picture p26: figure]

M3 machine screws + nuts

## SDOF-PWR-A01 | DC-DC converter to cover

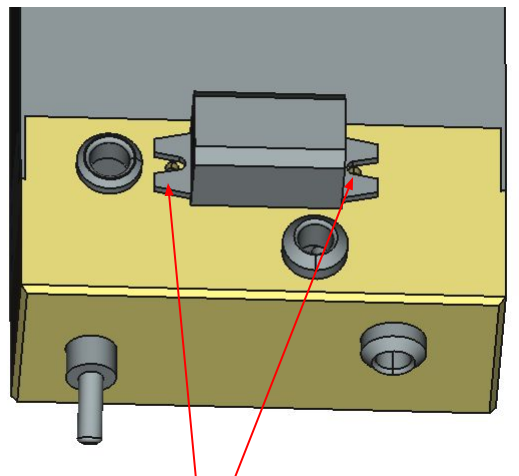
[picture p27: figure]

M3 machine screws + nuts

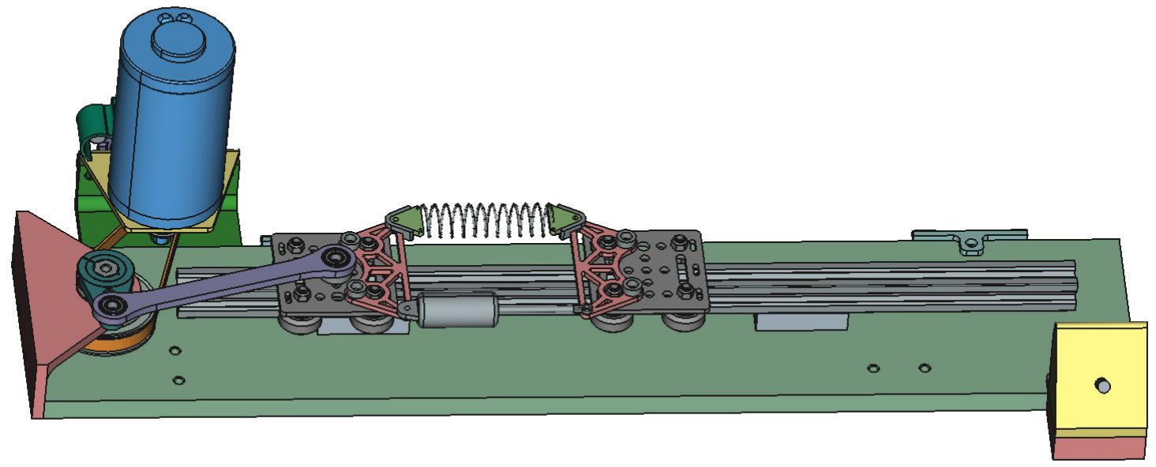
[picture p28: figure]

## SDOF-FREQ-A01 | Frequency Response Demo

## SDOF-FREQ-A01 | Crank

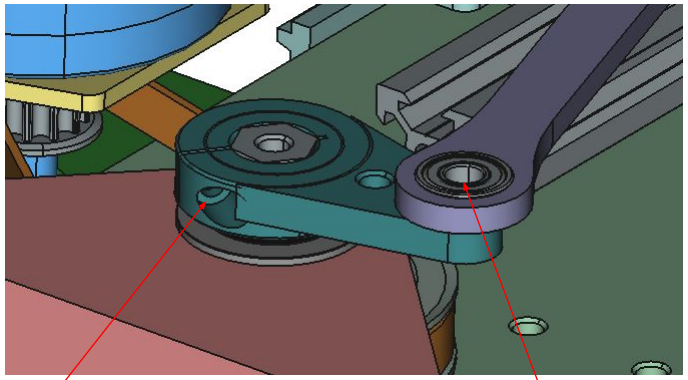
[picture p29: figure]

Pre-existing fastener (9/64” allen key) to tighten crank shaft-collar

¼-20 button head

## SDOF-FREQ-A01 | Linear rail to baseplate

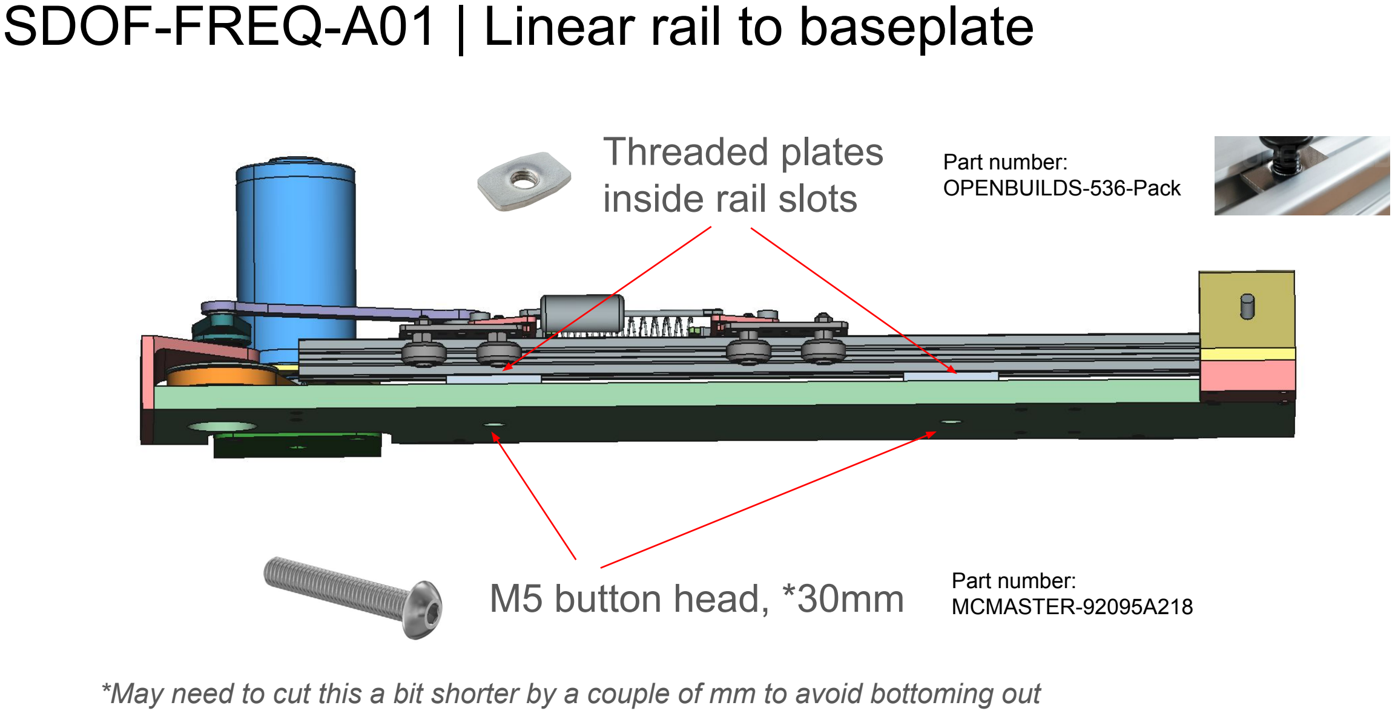
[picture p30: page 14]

M5 button head, *30mm

Threaded plates
inside rail slots

*May need to cut this a bit shorter by a couple of mm to avoid bottoming out

Part number:
MCMASTER-92095A218

Part number:
OPENBUILDS-536-Pack

## SDOF-FREQ-A01 | Mass-spring-damper assembly

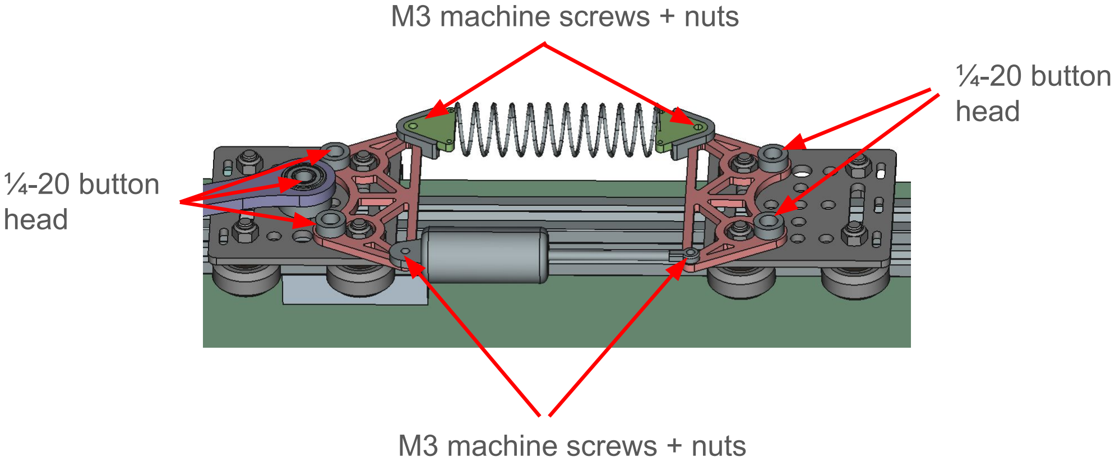
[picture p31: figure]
¼-20 button head; M3 machine screws + nuts

## SDOF-FREQ-A01 | Frequency module to baseplate

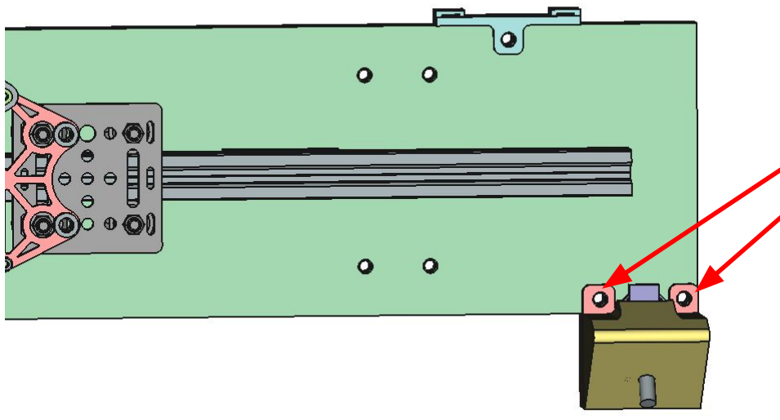
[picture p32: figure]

¼-20 button
head

## SDOF-FREQ-A02 | Frequency module lid to base

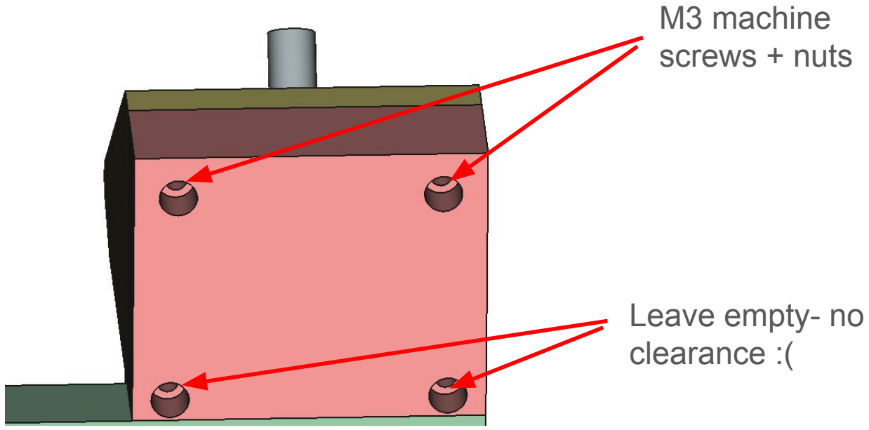
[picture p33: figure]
M3 machine screws + nuts; Leave empty- no clearance :(
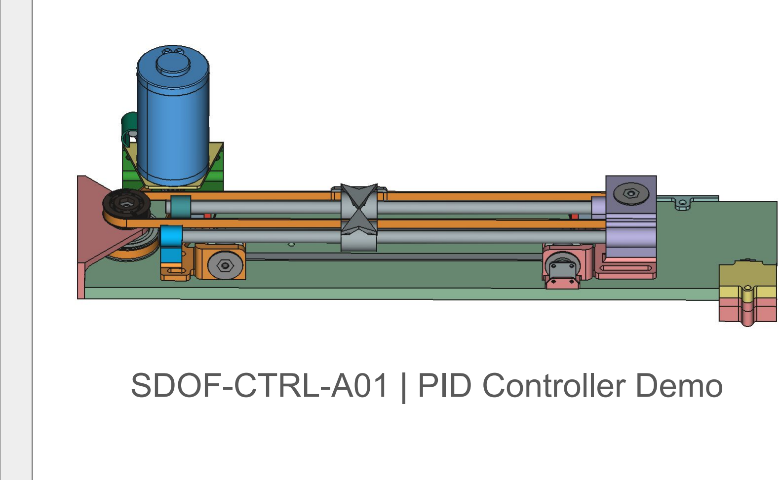
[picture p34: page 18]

## SDOF-CTRL-A01 | PID Controller Demo

## SDOF-CTRL-A01 | Drive pulley to crankshaft

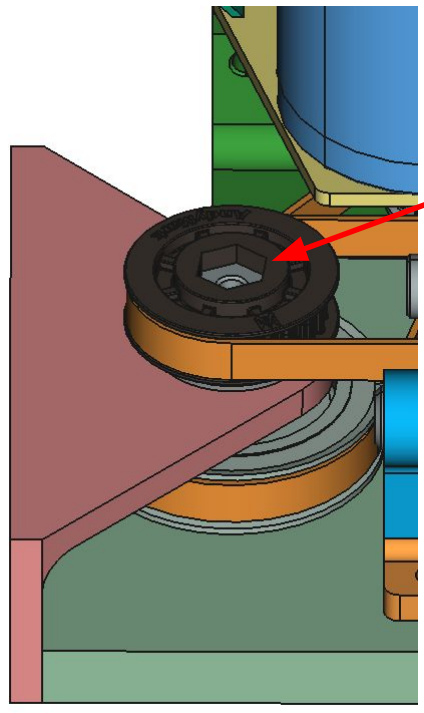
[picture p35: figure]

¼-20 button head,
0.625” long + flat
washer

## SDOF-CTRL-A01 | Motion assembly to baseplate

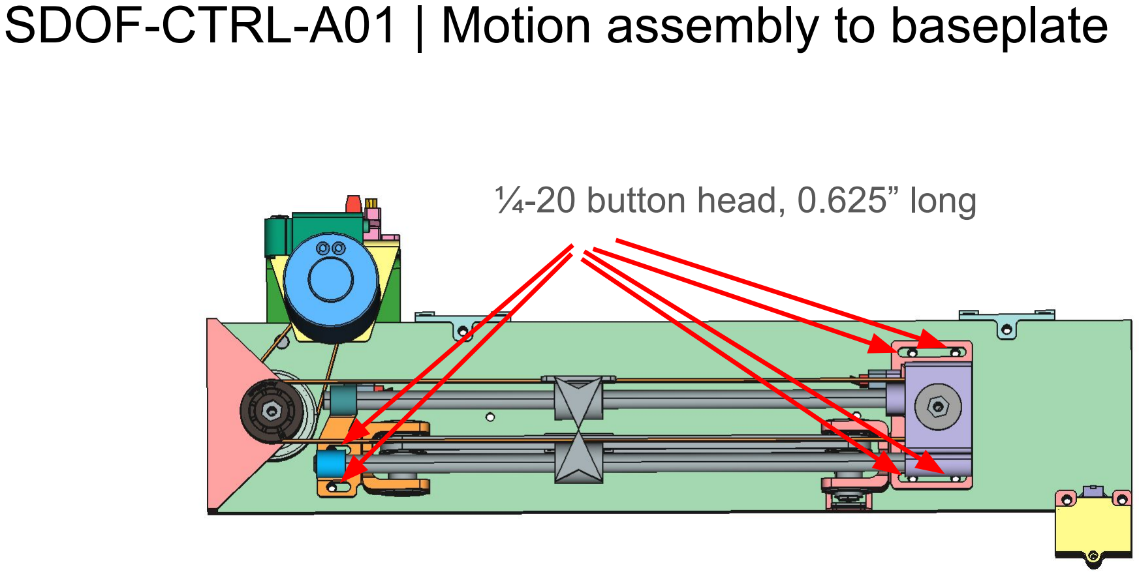
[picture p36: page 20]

¼-20 button head, 0.625” long

## SDOF-CTRL-A01 | Left input shaft

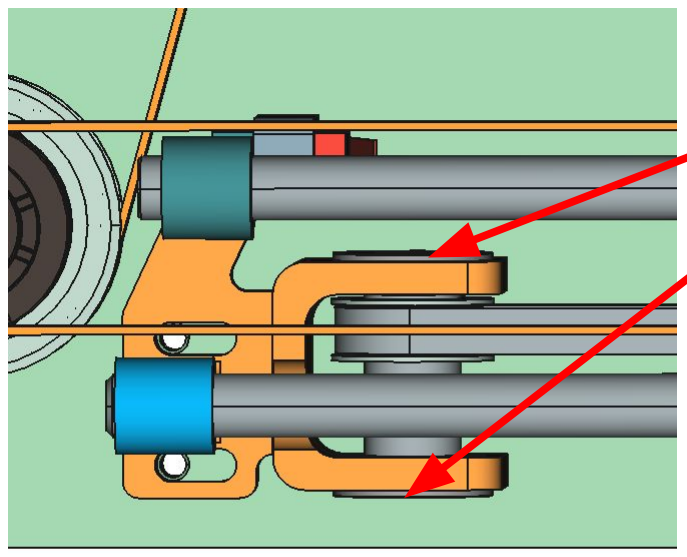
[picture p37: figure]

¼-20 button head,
0.625” long + flat
washer

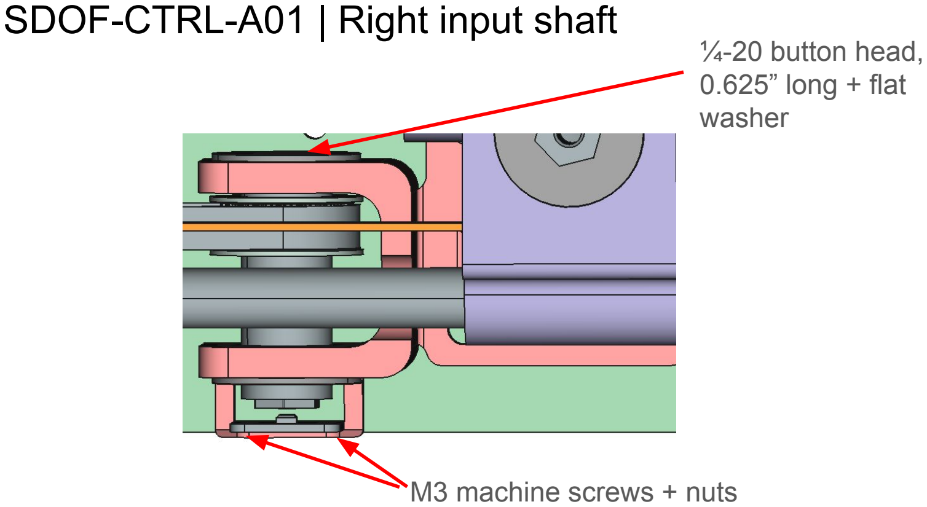
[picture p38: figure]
SDOF-CTRL-A01 | Right input shaft; ¼-20 button head, 0.625” long + flat washer; M3 machine screws + nuts

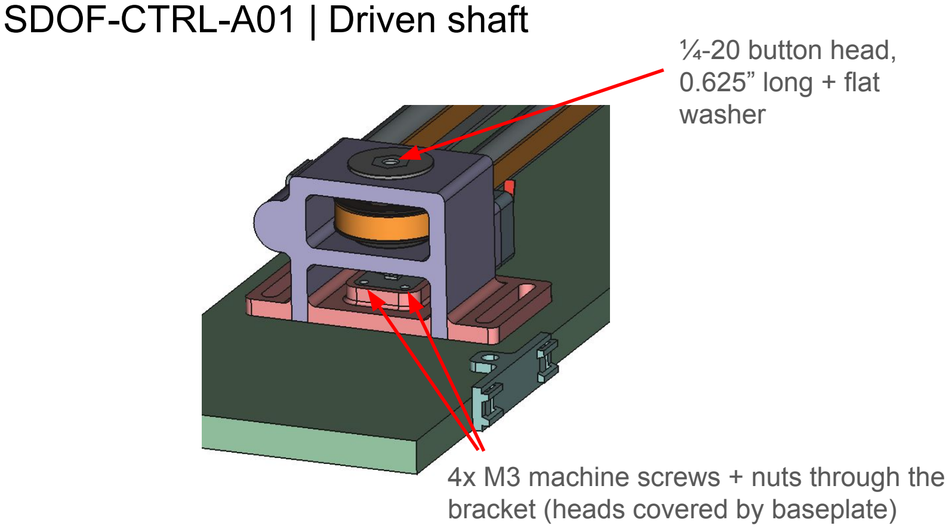
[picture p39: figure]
SDOF-CTRL-A01 | Driven shaft; ¼-20 button head, 0.625” long + flat washer; 4x M3 machine screws + nuts through the bracket (heads covered by baseplate)

## SDOF-CTRL-A01 | Control module to baseplate

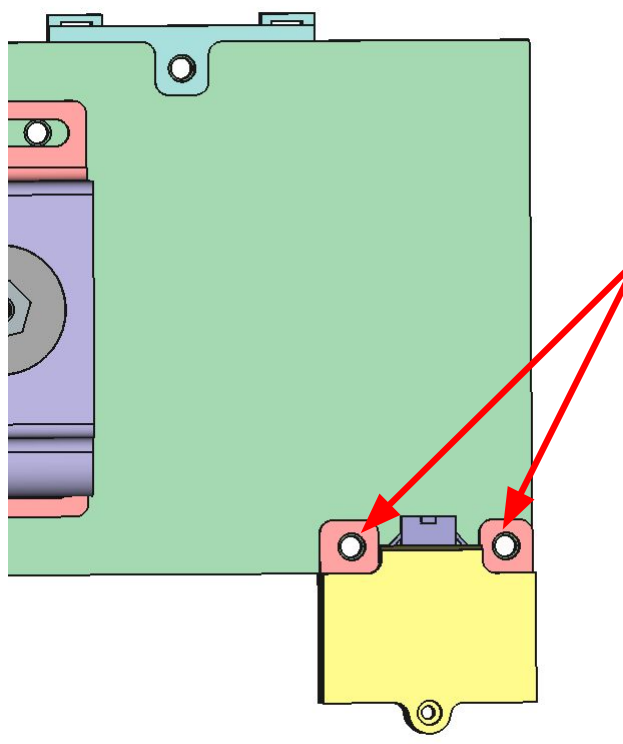
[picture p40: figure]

¼-20 button head,
0.625” long

## SDOF-CTRL-A02 | Control module lid to base

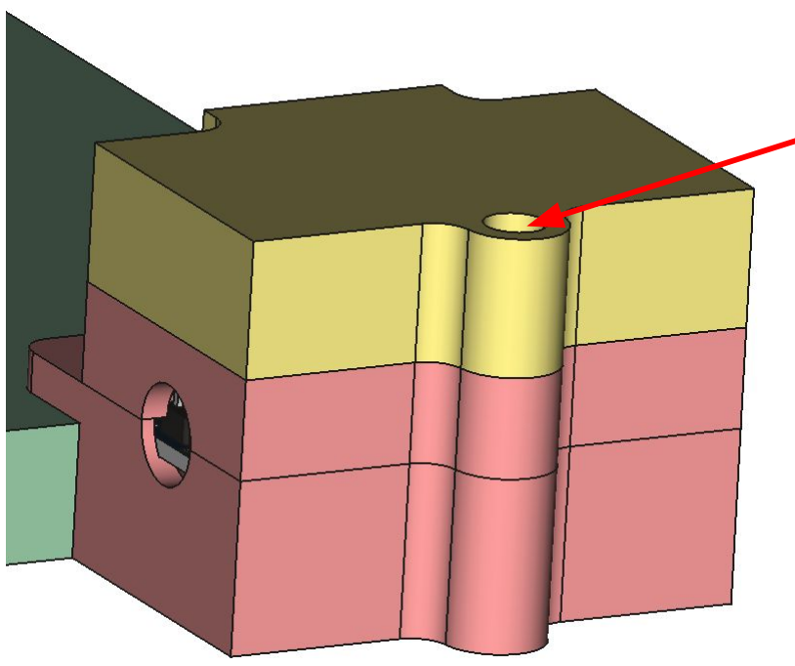
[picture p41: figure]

M3 machine
screws + nuts

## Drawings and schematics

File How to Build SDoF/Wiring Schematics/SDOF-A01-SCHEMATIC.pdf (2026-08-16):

# SDoF Demo Schematic | SDOF-A01 (Drive Base)

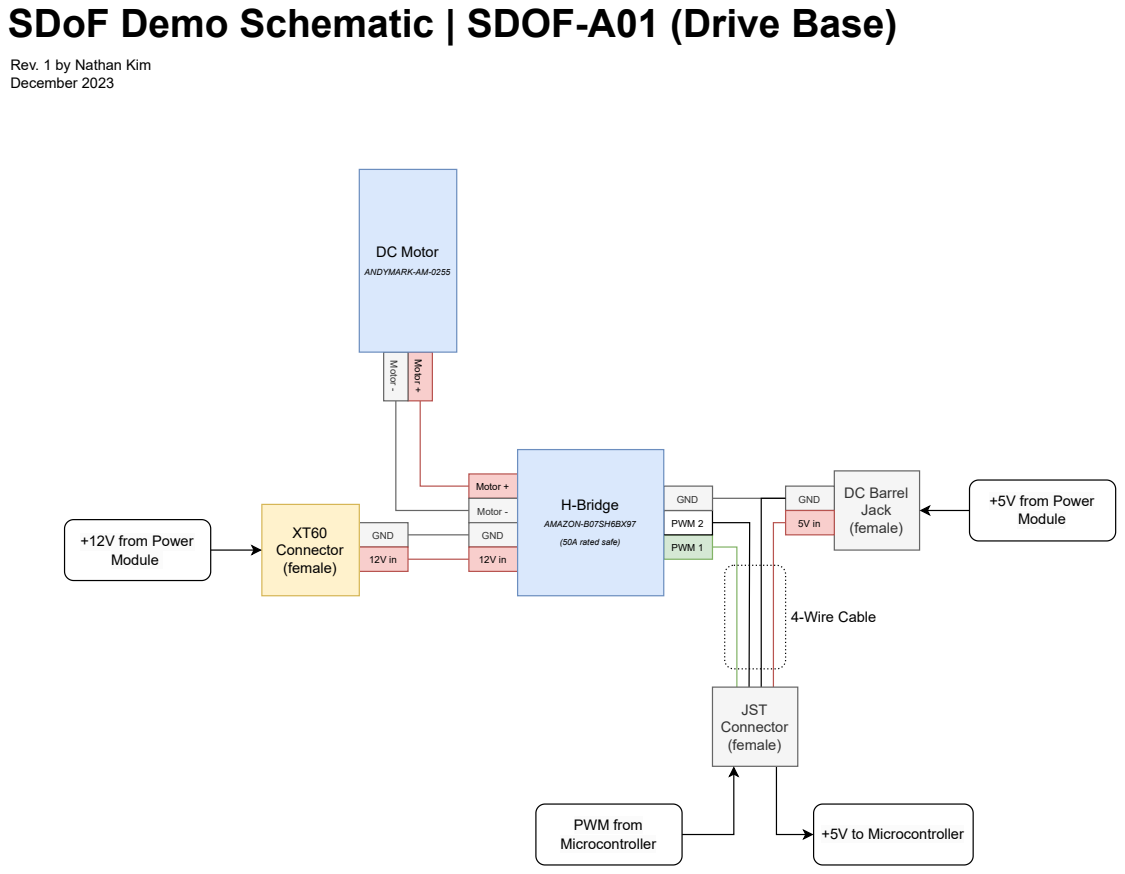
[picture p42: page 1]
Motor +; Motor -; GND; PWM 1; PWM 2; DC Barrel; Jack (female) GND; H-Bridge; AMAZON-B07SH6BX97; (50A rated safe); DC Motor; ANDYMARK-AM-0255; XT60 Connector (female); JST Connector (female); 4-Wire Cable; +12V from Power Module; PWM from; Microcontroller; +5V to Microcontroller; +5V from Power Module

Rev. 1 by Nathan Kim
December 2023

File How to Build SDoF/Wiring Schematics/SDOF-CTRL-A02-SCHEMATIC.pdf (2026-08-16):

# SDoF Demo Schematic | SDOF-CTRL-A02 (Control Module)

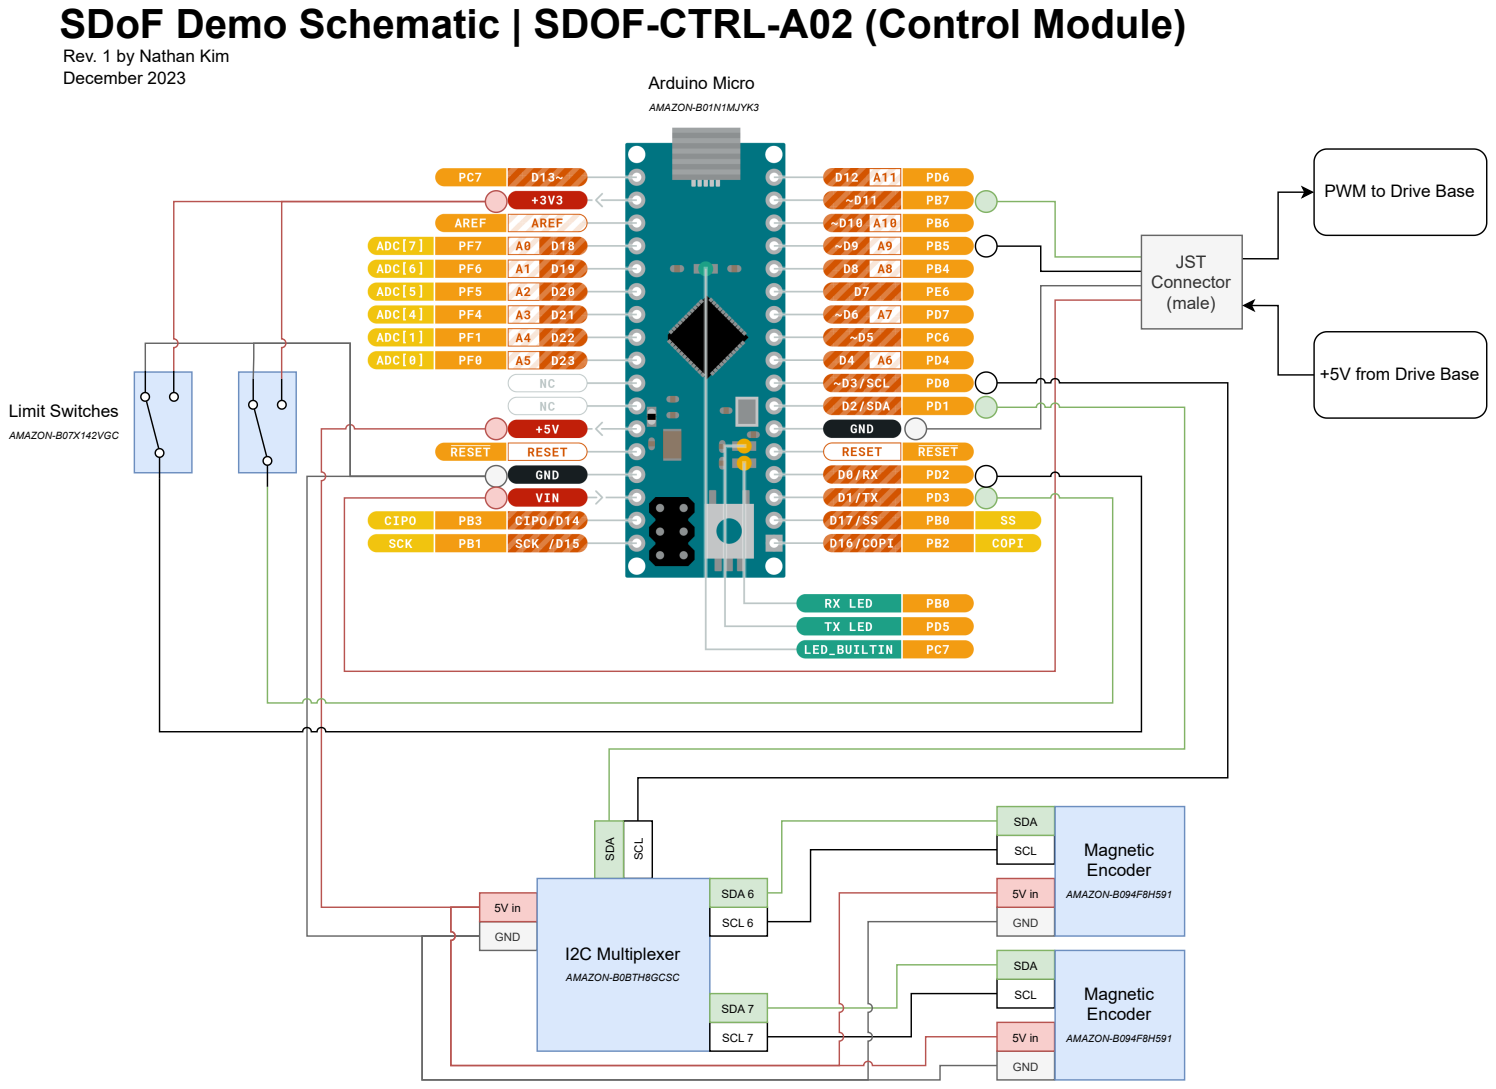
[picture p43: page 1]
Limit Switches; AMAZON-B07X142VGC; Arduino Micro; AMAZON-B01N1MJYK3; JST Connector (male); GND; SDA; SCL; Magnetic Encoder; AMAZON-B094F8H591

Rev. 1 by Nathan Kim
December 2023

PWM to Drive Base

+5V from Drive Base

I2C Multiplexer AMAZON-B0BTH8GCSC | SDA 6 | 5V in

SCL 6 | GND

SDA 7

SCL 7 | 5V in

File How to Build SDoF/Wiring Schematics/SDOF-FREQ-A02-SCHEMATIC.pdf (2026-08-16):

# SDoF Demo Schematic | SDOF-FREQ-A02 (Frequency Module)

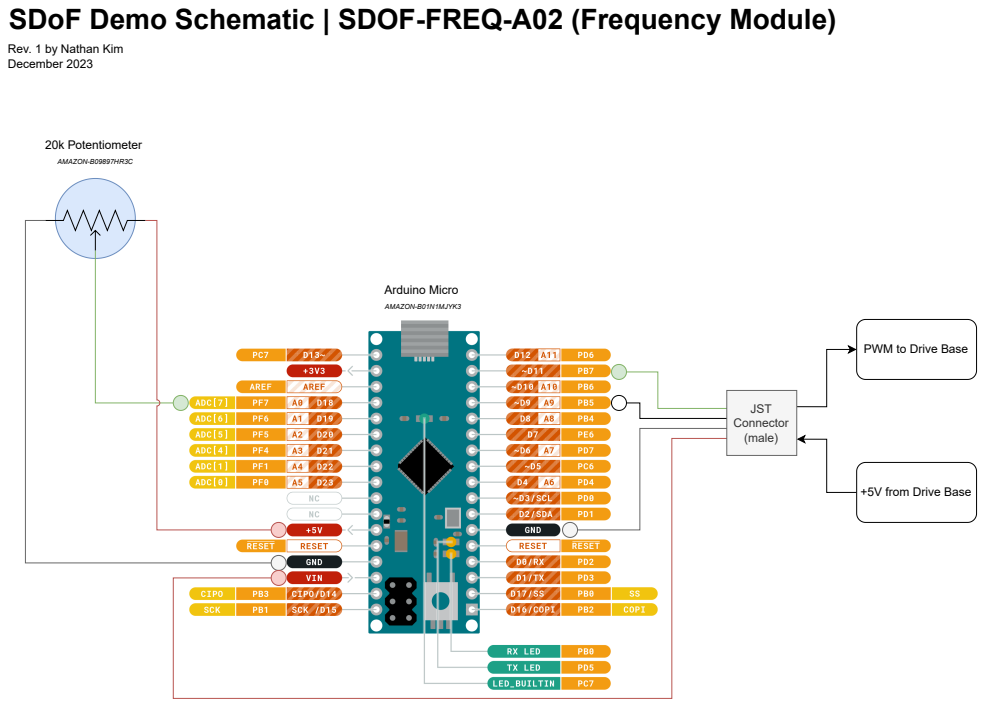
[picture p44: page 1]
20k Potentiometer; AMAZON-B09897HR3C; Arduino Micro; AMAZON-B01N1MJYK3; JST Connector (male)

Rev. 1 by Nathan Kim
December 2023

PWM to Drive Base

+5V from Drive Base

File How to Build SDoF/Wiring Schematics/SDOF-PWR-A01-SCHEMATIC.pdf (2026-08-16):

# SDoF Demo Schematic | SDOF-PWR-A01 (Power Module)

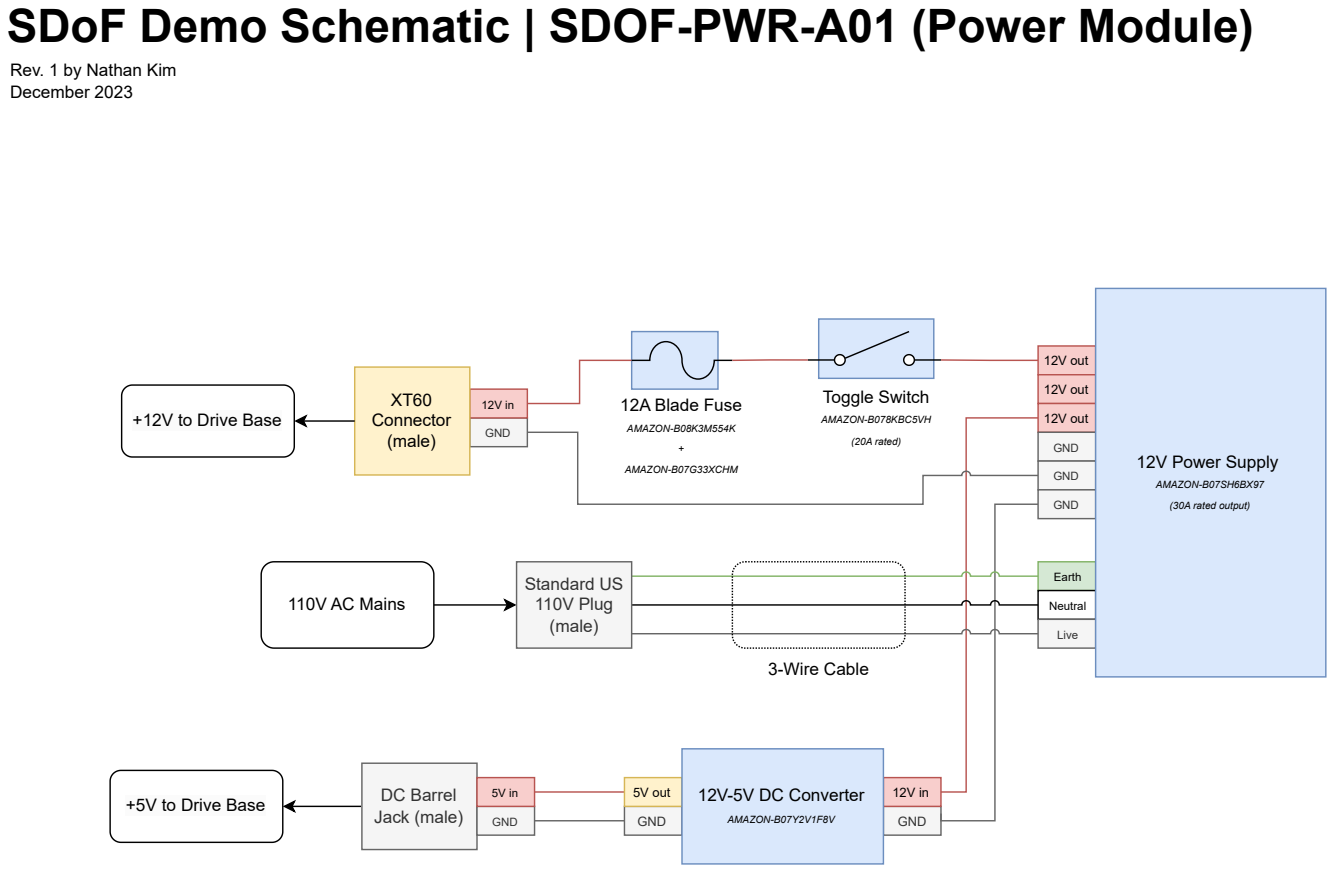
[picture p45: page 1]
GND; 5V out; 12V out; Earth; Neutral; Live; Toggle Switch; AMAZON-B078KBC5VH; (20A rated); 12A Blade Fuse; AMAZON-B08K3M554K; AMAZON-B07G33XCHM; 3-Wire Cable; 110V AC Mains; Standard US 110V Plug (male); 12V Power Supply; AMAZON-B07SH6BX97; (30A rated output); Connector (male); 12V-5V DC Converter; AMAZON-B07Y2V1F8V; +5V to Drive Base; DC Barrel; Jack (male)

Rev. 1 by Nathan Kim
December 2023

+12V to Drive Base

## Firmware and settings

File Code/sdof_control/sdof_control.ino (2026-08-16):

// First iteration code for the SDoF control demo. Rough sketch to run on an Arduino Micro.
// Written Fall 2023 by Nathan Kim (nathnkim@umich.edu) for MECHENG 360 with Dr. Jeffrey Koller at the University of Michigan - Ann Arbor.

#include "AS5600.h" // Library for the magnetic encoders https://github.com/RobTillaart/AS5600
#include "Wire.h" // Library for using the I2C communication protocol https://www.arduino.cc/reference/en/language/functions/communication/wire/
#include "TCA9548.h" // Library for using the I2C multiplexer https://github.com/RobTillaart/TCA9548

// Instantiating peripheral components per their respective libraries
TCA9548 multiplexer(0x70); // I2C address of multiplexer is 0x70 per datasheet
AS5600 inputEncoder; 
AS5600 outputEncoder; 

uint8_t encoderAddress = 0x36; // I2C address of encoders

const int inputEncoderChannel = 7; // Input encoder channel on multiplexer
const int outputEncoderChannel = 6; // Output encoder channel on multiplexer

const int pwmOutputPin_neg = 9;  // PWM output pin on Arduino
const int pwmOutputPin_pos = 11; // PWM output pin on Arduino

const int limitSwitchPin_left = 1; //Left bound limit switch interrupt pin on Arduino
const int limitSwitchPin_right = 0; //Right bound limit switch interrupt pin on Arduino

const double inputPulleyRadius = 0.5375; // inches, for calculating linear distance of input pointer
const double outputPulleyRadius = 0.7275; // inches, for calculating linear distance of driven pointer

double inputTotalRotations = 0.0;  // Variable to keep track of total rotations of input pulleys
double outputTotalRotations = 0.0;  // Variable to keep track of total rotations of driven pulleys

double inputLastAngle = 0.0; // Variable to keep track of previous position of of input pulley
double outputLastAngle = 0.0; // Variable to keep track of previous position of of driven pulley

double inputAngle, outputAngle, inputAngleOffset, outputAngleOffset, inputPos, outputPos; // Variables to track states and some offsets

double previousError = 0.0; // Track previous error for PID computation
double integral = 0.0; // To integrate error for PID computation

unsigned long previousTime = 0; // To store low bound of dt for derivative of error de/dt

///////////////////////////////////////////////////////////////////////////////////////////////////////////////////////
// Edit PID gains here
double Kp = 150.;
double Ki = 50.;
double Kd = 5.;

const unsigned int pwmLimit = 155; //Saturate PWM duty cycle output (on [0,255] in Arduinoland) to prevent overcurrent
///////////////////////////////////////////////////////////////////////////////////////////////////////////////////////

// void setup() is code that runs once on the Arduino when powered on. Pins are initialized, interrupts are attached, library preliminaries are handled.
void setup() {
  // Intializing all pins that the Arduino takes input from or provides output to (I/O)
  pinMode(pwmOutputPin_neg, OUTPUT);
  pinMode(pwmOutputPin_pos, OUTPUT);
  pinMode(limitSwitchPin_left, INPUT);
  pinMode(limitSwitchPin_right, INPUT);

  // AS5600.h library preliminaries for reading the encoder (see library documentation)
  inputEncoder.begin(4);  //  set direction pin.
  inputEncoder.setDirection(AS5600_CLOCK_WISE);  // default, just be explicit.
  outputEncoder.begin(4);  //  set direction pin.
  outputEncoder.setDirection(AS5600_CLOCK_WISE);  // default, just be explicit.
  
  // The following chunk sets the encoder offsets (since the encoders are absolute) which are used to zero the position of the pointers.
  // The implication of this is that with this code, regardless of where the pointers are in real life, the Arduino will think
  // they are pointing right at each other due to this offset calculation.
  multiplexer.selectChannel(inputEncoderChannel); // set multiplexer to read input encoder
  inputAngleOffset = inputEncoder.rawAngle() * AS5600_RAW_TO_RADIANS; // read current angle, convert to radians
  multiplexer.selectChannel(outputEncoderChannel);// set multiplexer to read output encoder
  outputAngleOffset = outputEncoder.rawAngle() * AS5600_RAW_TO_RADIANS; // read current angle, convert to radians

  // "Attach" the limit switch interrupts- tell the Arduino to stop doing what its doing when a limit switch is pressed and save the demo from destroying itself.
  attachInterrupt(digitalPinToInterrupt(limitSwitchPin_left), leftLimitSwitchISR, RISING); // When the Arduino detects a rising edge on the left limit switch pin indicating it has been pressed,
                                                                                           // immediately stop what its doing and execute the `leftLimitSwitchISR` function.
  attachInterrupt(digitalPinToInterrupt(limitSwitchPin_right), rightLimitSwitchISR, RISING); // When the Arduino detects a rising edge on the right limit switch pin indicating it has been pressed,
                                                                                            // immediately stop what its doing and execute the `rightLimitSwitchISR` function.

  // Open serial communication for debugging https://docs.arduino.cc/software/ide-v2/tutorials/ide-v2-serial-monitor/
  Serial.begin(115200);
}

//*****************void loop() is code that runs infinitely once setup() is executed, until the Arduino is powered off.*******************************************
void loop() {
  inputPos = inputGetPosition(); //Read and store current position of input pointer
  outputPos = outputGetPosition(); //Read and store current position of output pointer

  int pwm = computePID(inputPos, outputPos); // Use PID controller to compute PWM duty cycle to apply to motor based on the pointer positions
  
  // If controller commands negative rotation, PWM duty cycle will be negative- the following code catches thus case and corrects PWM sign
  // while sdirecting the command to the negative rotation PWM input on the H-bridge 
  if (pwm < 0){
    if (pwm < (-1 * pwmLimit)){ // Saturate the duty cycle at the preset limit
      pwm = -1 * pwmLimit;
    }
    pwm *= -1;
    analogWrite(pwmOutputPin_neg, pwm);

    //Uncomment below to debug via Serial monitor and see what the commanded PWM duty cycle is
    //Serial.print("PWM Neg : "); 
    //Serial.println(pwm);

  }
  else{
    if (pwm > pwmLimit){ // Saturate the duty cycle at the preset limit
      pwm = pwmLimit;
    }
    analogWrite(pwmOutputPin_pos, pwm);

    //Uncomment below to debug via Serial monitor and see what the commanded PWM duty cycle is
    //Serial.print("PWM Pos : ");
    //Serial.println(pwm);
  }
}

//*********************** Function to print angles to serial monitor for debugging *****************************************************
void printAngles(){
  multiplexer.selectChannel(inputEncoderChannel);
  inputAngle = inputEncoder.rawAngle() * AS5600_RAW_TO_DEGREES;
  multiplexer.selectChannel(outputEncoderChannel);
  outputAngle = outputEncoder.rawAngle() * AS5600_RAW_TO_DEGREES;

  Serial.print("Input Angle : ");
  Serial.print(inputAngle);
  Serial.print("            Output Angle : ");
  Serial.println(outputAngle);
  delay(100);
}

//*********************** Function to get the position of the input pointer************************************************************
double inputGetPosition() {
  multiplexer.selectChannel(inputEncoderChannel); // Set multiplexer to read input encoder
  inputAngle = inputEncoder.rawAngle() * AS5600_RAW_TO_RADIANS - inputAngleOffset; // Compute input angle displaced from 0 set by offset
  
  // Calculate the change in angle since the last call
  double angleChange = inputAngle - inputLastAngle;

  // Update the total number of rotations if there is actual rotation
  if (angleChange > M_PI) {
    inputTotalRotations -= 1.0;  // Handle case where angle goes backward across 2*pi
  } else if (angleChange < -M_PI) {
    inputTotalRotations += 1.0;  // Handle case where angle goes forward across 2*pi
  }
  
  // Convert the angle to linear position, preserving accumulated rotations
  double linearPosition = (inputAngle * inputPulleyRadius) + (inputTotalRotations * TWO_PI * inputPulleyRadius);

  inputLastAngle = inputAngle;
  return linearPosition;

  //Uncomment below to debug via Serial monitor 
  //Serial.println(linearPosition);
}

//*********************** Function to get the position of the output pointer ************************************************************
double outputGetPosition() {
  multiplexer.selectChannel(outputEncoderChannel); // Set multiplexer to read driven encoder
  outputAngle = -1.*(outputEncoder.rawAngle() * AS5600_RAW_TO_RADIANS - outputAngleOffset); // Compute input angle displaced from 0 set by offset
  
  // Calculate the change in angle since the last call
  double angleChange = outputAngle - outputLastAngle;
  // Update the total number of rotations if there is actual rotation
  if (angleChange > M_PI) {
    outputTotalRotations -= 1.0;  // Handle case where angle goes backward across 2*pi
  } else if (angleChange < -M_PI) {
    outputTotalRotations += 1.0;  // Handle case where angle goes forward across 2*pi
  }
  
  // Convert the angle to linear position, preserving accumulated rotations
  double linearPosition = (outputAngle * outputPulleyRadius) + (outputTotalRotations * TWO_PI * outputPulleyRadius);

  outputLastAngle = outputAngle;
  return linearPosition;

  //Uncomment below to debug via Serial monitor 
  //Serial.println(linearPosition);
}

//********************** Function to implement PID control law *********************************************************************
double computePID(double setpoint, double sensorValue) {
  
  unsigned long currentTime = millis(); // Get the current time

  unsigned long dt = currentTime - previousTime; // Calculate the time difference since the last iteration
  
  double error = setpoint - sensorValue;  // Calculate the error
  integral += error * dt / 1000.0; // Calculate the integral of the error, dt is converted to seconds
  double derivative = (error - previousError) / (dt / 1000.0);  // Calculate the derivative of the error, dt is converted to seconds
  double output = Kp * error + Ki * integral + Kd * derivative; // Calculate the control output

  // Update variables for the next iteration
  previousError = error;
  previousTime = currentTime;

  return output;
}

//********************** Function to implement safing routine when pointer bottoms out on leftmost limit switch *********************
void leftLimitSwitchISR(){
  // EDIT THIS- RIGHT NOW IT DOES NOTHING
  // Uncomment below to test limit switch via serial monitor
  //Serial.println("Left bound touched");
  }
//********************** Function to implement safing routine when pointer bottoms out on rightmost limit switch *********************  
void rightLimitSwitchISR(){
  // EDIT THIS- RIGHT NOW IT DOES NOTHING
  // Uncomment below to test limit switch via serial monitor
  //Serial.println("Right bound touched");
  }

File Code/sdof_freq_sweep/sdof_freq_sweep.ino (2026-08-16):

// First iteration code for the SDoF control demo. Rough sketch to run on an Arduino Micro.
// Written Fall 2023 by Nathan Kim (nathnkim@umich.edu) for MECHENG 360 with Dr. Jeffrey Koller at the University of Michigan - Ann Arbor.

const int potentiometerPin = 18; // Arduino pin connected to the potentiometer. Be careful about how ground and Vcc are connected, they could cause potentiometer reading increase with different rotation driections.
const int pwmOutputPin_pos = 9;  // Arduino PWM output pin 
const int pwmOutputPin_neg = 11; // Arduino PWM output pin

// void setup() is code that runs once on the Arduino when powered on. Pins are initialized, library preliminaries are handled.
void setup() {
  pinMode(pwmOutputPin_pos, OUTPUT);
  pinMode(pwmOutputPin_neg, OUTPUT);
  // Serial.begin(9600); // Uncomment if printing sensor value
}

//void loop() is code that runs infinitely once setup() is executed, until the Arduino is powered off.
void loop() {
  // Read the value from the potentiometer
  int sensorValue = analogRead(potentiometerPin);

  // Map the sensor value to a range of 0-255 (for PWM)
  int pwmValue = map(sensorValue, 0, 1023, 0, 255);

  /* // Print the sensor value and PWM value to the Serial Monitor
  Serial.print("Sensor Value: ");
  Serial.print(sensorValue);
  Serial.print(" | PWM Value: ");
  Serial.println(pwmValue);
  */

  // Write the PWM value to the PWM output pin
  analogWrite(pwmOutputPin_pos, pwmValue);
}
